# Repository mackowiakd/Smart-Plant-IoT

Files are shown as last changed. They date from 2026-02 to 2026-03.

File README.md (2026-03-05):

> 🎓 **Academic Project**: This project was developed for the *Microprocessor and Embedded Systems* course during the 5th semester of Computer Science at the **Silesian University of Technology** (Politechnika Śląska).

# Smart Plant Care IoT System 🌱

An end-to-end Internet of Things (IoT) solution for monitoring environmental parameters and autonomously managing plant hydration. The project spans custom hardware design (PCB), edge device firmware (ESP32-C3), and a full-stack web dashboard.

## 🌟 Key Features
* **Smart Autonomous Watering:** Activates a water pump based on custom-calibrated soil moisture data (`AIR_VALUE` & `WATER_VALUE`). The logic includes safety checks, such as preventing watering during low temperatures to protect the plant roots.
* **Extreme Power Optimization:** Heavily utilizes the ESP32 **Deep Sleep** mode. The system wakes up periodically, performs measurements, communicates with the server, and goes back to sleep, allowing for long-term operation on a standard 5V powerbank.
* **Fail-Safe Offline Mode (Fallback AP):** If the configured WiFi network is lost, the device automatically spawns its own Access Point (e.g., "Roslina SOS"). It serves a lightweight local HTML page (`WebPage.h`) directly to a smartphone, allowing the user to view telemetry without internet access.
* **Hybrid Timekeeping:** Combines internet time synchronization (NTP) with a battery-backed hardware Real-Time Clock (DS3231) to maintain time context and scheduling during power losses or offline periods.
* **Full-Stack SPA Architecture:** Telemetry is pushed via HTTP to a custom .NET backend, which seamlessly serves a modern React-based user dashboard.

## 🛠️ System Architecture & Tech Stack

### 1. Edge Device (Firmware & Hardware)
* **Microcontroller:** Seeed Studio XIAO ESP32-C3.
* **Sensors & Actuators:** * **BME280** (Temperature, Humidity, Atmospheric Pressure) via I2C.
  * **BH1750** (Light intensity/Lux) via I2C.
  * **DS3231** (Hardware RTC) via I2C.
  * **Capacitive Soil Moisture Sensor v1.2** via ADC.
  * 5V Water Pump controlled via MOSFET/Relay.
* **Firmware:** C++, PlatformIO, custom sleep/wake routines.

### 2. Web Application (Backend & Frontend)
* **Architecture:** Single Page Application (SPA) integration.
* **Backend:** C#, ASP.NET Core REST API for telemetry data ingestion and aggregation.
* **Frontend:** React.js, Vite, and Tailwind CSS for responsive data visualization.

## 📸 Project Gallery

smart_plant_hardware

  **Figure 1: Custom PCB & Hardware Assembly.** *The physical implementation of the project. I designed the schematic and routed the custom PCB using **KiCad** to seamlessly integrate the XIAO ESP32-C3 with various modules: an I2C environment sensor array (including BH1750), a battery-backed RTC, and the power delivery circuitry. The entire system is optimized to run autonomously on a standard 5V powerbank utilizing Deep Sleep cycles.*


  **Figure 1: Custom PCB & Hardware Assembly.** Showing the XIAO ESP32-C3 integration with environmental sensors and the watering unit running on powerbank supply.

 

https://github.com/user-attachments/assets/34abda69-28c0-408e-982a-c36de282d4bd

  **Figure 2: React Dashboard.** Visualizing real-time telemetry data (humidity, temperature, pressure, light) received from the .NET REST API.

https://github.com/user-attachments/assets/e299edc5-c103-400d-92fd-4557b35e483f

  **Figure 3: Emergency Offline Mode.** The lightweight captive portal/HTML page served directly by the ESP32 when external WiFi is unavailable.

## 🚀

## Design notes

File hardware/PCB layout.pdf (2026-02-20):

1. Wersja "BEZ WYLANEJ MASY" ( Top/Bottom )

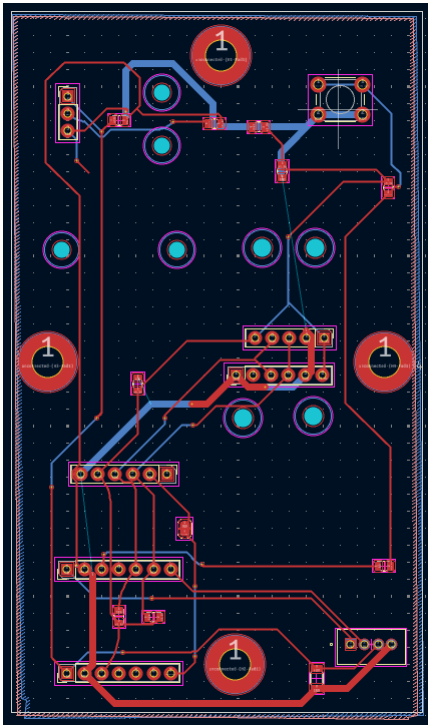
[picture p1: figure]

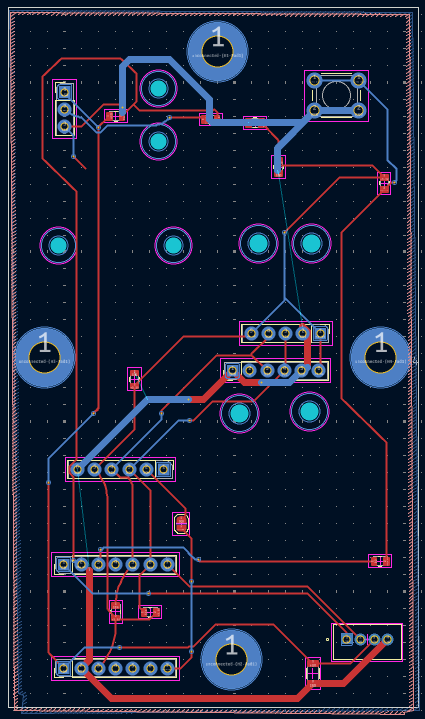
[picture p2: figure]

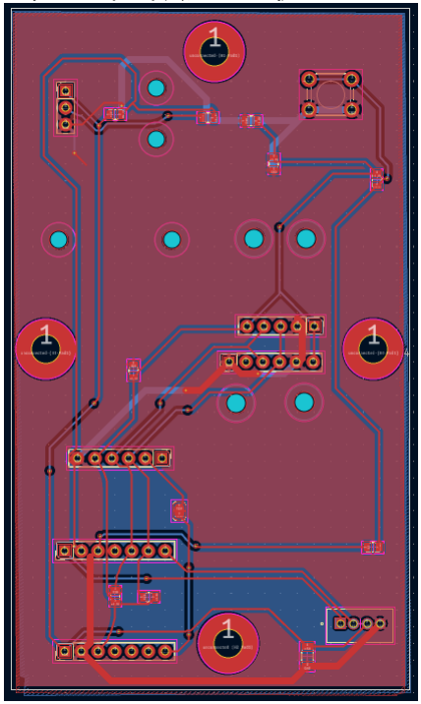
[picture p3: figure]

2. Wersja "Z WYLANĄ MASĄ" (Top/Bottom z masą)

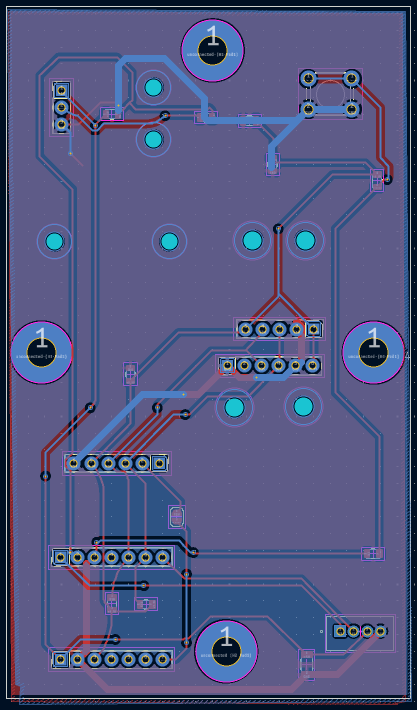
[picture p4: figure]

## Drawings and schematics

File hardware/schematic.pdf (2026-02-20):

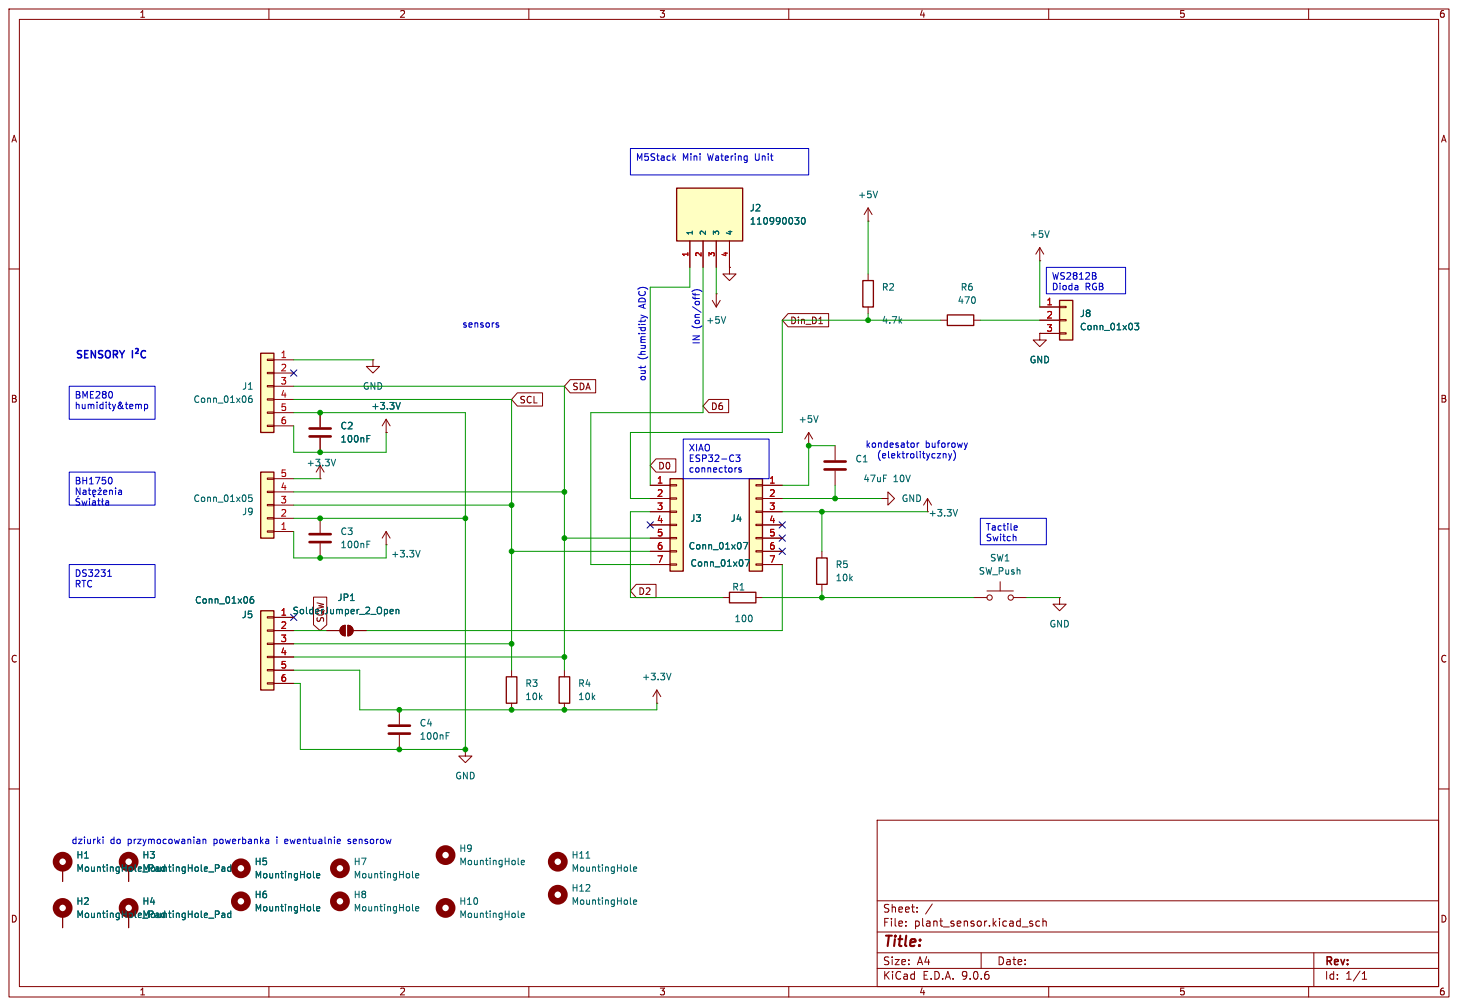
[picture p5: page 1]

4 4
5 5

Id: 1/1 Title: File: plant_sensor.kicad_sch Sheet: /

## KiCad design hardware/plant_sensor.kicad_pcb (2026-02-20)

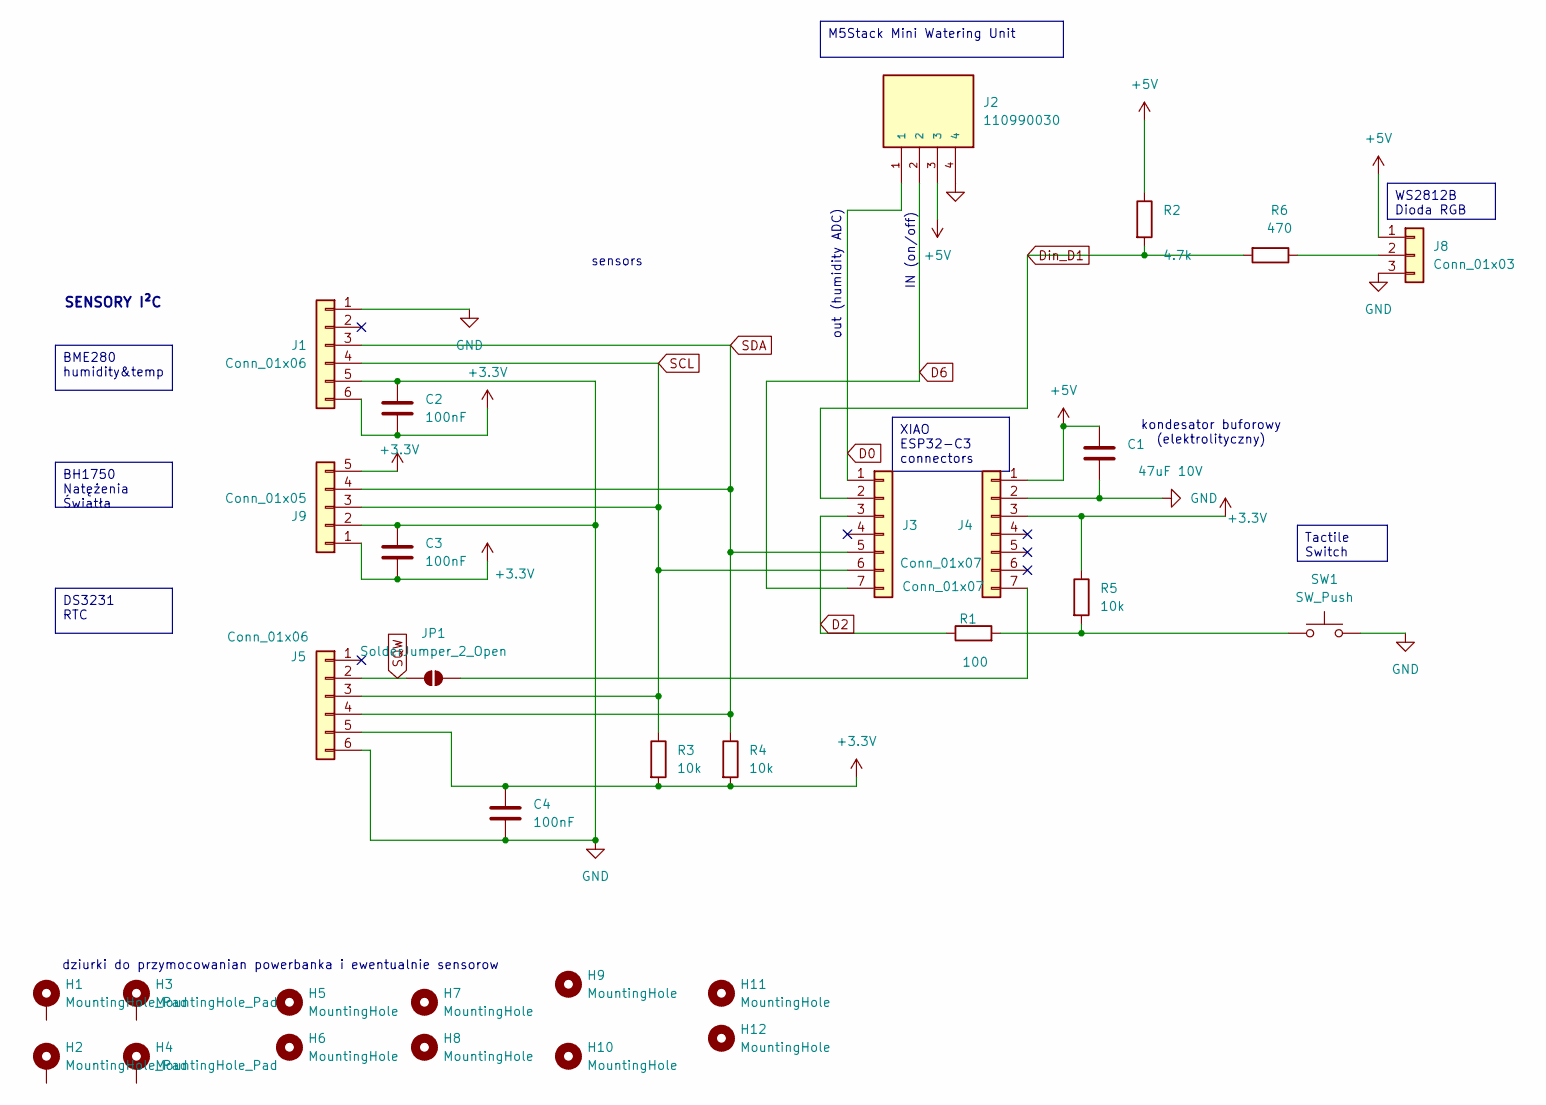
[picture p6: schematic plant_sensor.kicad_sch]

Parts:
C1: 47uF 10V; C_1206_3216Metric; LCSC Part # C13608
C2, C3, C4: 100nF; C_0805_2012Metric; LCSC Part # C49678
H1, H2, H3, H4: MountingHole_Pad; MountingHole_4.3mm_M4_Pad
H5, H6, H7, H8: MountingHole; MountingHole_2.7mm
H9, H10, H11, H12: MountingHole; MountingHole_2.5mm
J1, J5: Conn_01x06; PinHeader_1x06_P2.54mm_Vertical; LCSC Part # C50982
J2: 110990030; SEEED_110990030; PARTREV A; LCSC Part # C52230
J3, J4: Conn_01x07; PinHeader_1x07_P2.54mm_Vertical; LCSC Part # C2254
J8: Conn_01x03; PinHeader_1x03_P2.54mm_Vertical; LCSC Part # C124398
J9: Conn_01x05; PinHeader_1x05_P2.54mm_Vertical; LCSC Part # C2251
JP1: SolderJumper_2_Open; SolderJumper-2_P1.3mm_Open_RoundedPad1.0x1.5mm
R1: 100; R_0805_2012Metric; LCSC Part # C17408
R2: 4.7k; R_0805_2012Metric; LCSC Part # C17673
R3, R4, R5: 10k; R_0805_2012Metric; LCSC Part # C17414
R6: 470; R_0805_2012Metric; LCSC Part # C17710
SW1: SW_Push; SW_PUSH_6mm; LCSC Part # C318884

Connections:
+3.3V: C2.2, C3.2, C4.1, J1.6, J4.3, J5.5, J9.1, J9.5, R3.2, R4.2, R5.1
+5V: C1.1, J2.3, J4.1, J8.1, R2.1
D0: J2.1, J3.1
D2: J3.3, R1.1
D6: J2.2, J3.7
Din_D1: J3.2, R2.2, R6.2
GND: C1.2, C2.1, C3.1, C4.2, J1.1, J1.5, J2.4, J4.2, J5.6, J8.3, J9.2, SW1.2
unnamed: J4.7, JP1.2 (B)
unnamed: J8.2, R6.1
unnamed: R1.2, R5.2, SW1.1
SCL: J1.4, J3.6, J5.3, J9.3, R3.1
SDA: J1.3, J3.5, J5.4, J9.4, R4.1
SQW: J5.2, JP1.1 (A)

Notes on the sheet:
sensors
IN (on/off)
SENSORY I²C
dziurki do przymocowanian powerbanka i ewentualnie sensorow
kondesator buforowy (elektrolityczny)
out (humidity ADC)
M5Stack Mini Watering Unit
XIAO ESP32-C3 connectors
BME280 humidity&temp
WS2812B Dioda RGB
BH1750 Natężenia Światła
Tactile Switch
DS3231 RTC

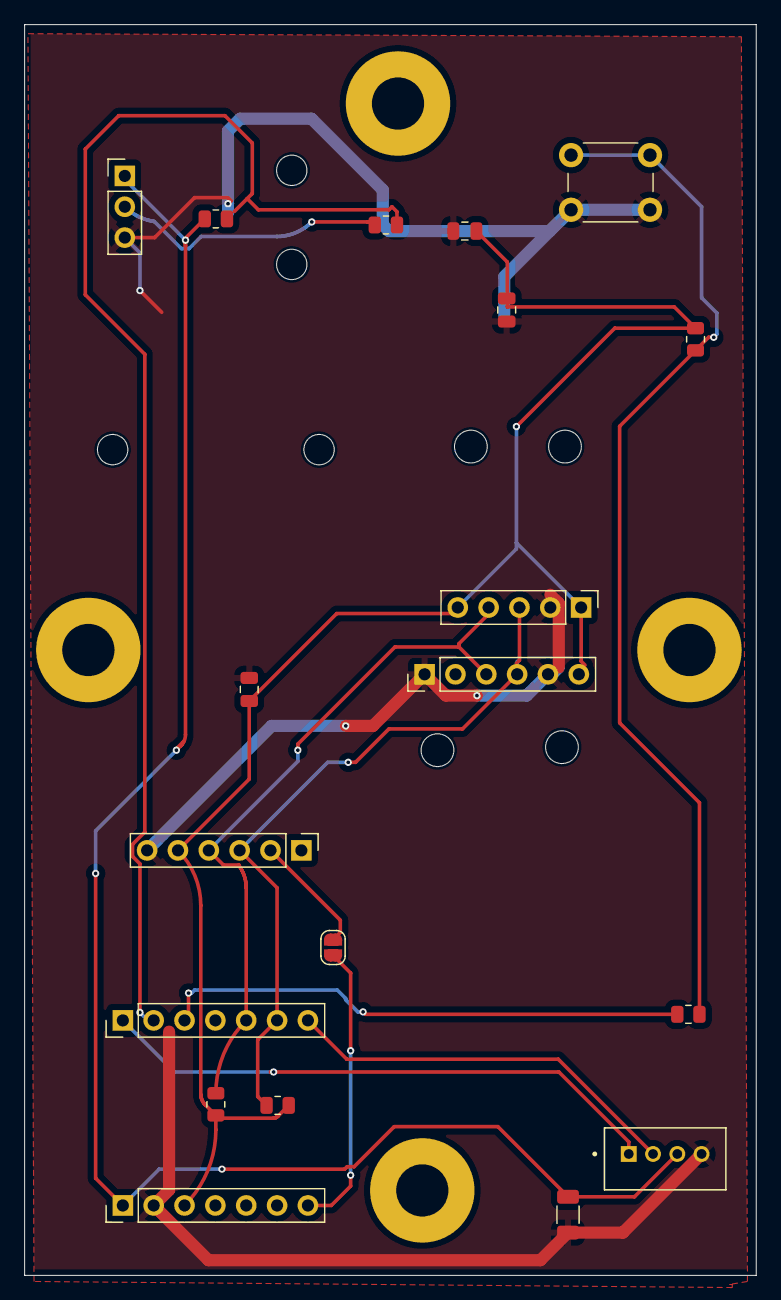
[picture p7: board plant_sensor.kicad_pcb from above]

Board: 2 copper layers, 60.2 x 103.0 mm, 31 parts (0 on the bottom side), 13 nets.

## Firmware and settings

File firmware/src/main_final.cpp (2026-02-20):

#include <Arduino.h>
#include "Logic/plant entity/PlantManager.h" 

// --- KONFIGURACJA ---
#define PIN_SDA 6
#define PIN_SCL 7
#define PIN_PUMP 21     
#define PIN_MOIST 2     
#define PIN_LED 3       
#define PIN_BTN 4       

// Obiekty
PlantManager manager(new Indicator(PIN_LED, PIN_BTN), new WateringUnit(PIN_PUMP, PIN_MOIST), new RealTimeClock());

// Zmienne
bool interactiveMode = true; // ZAWSZE TRUE - bo zawsze chcemy wejść do loop
unsigned long lastActivityTime = 0;

void setup() {
    Serial.begin(115200);
    
    // Safety delay (żebyś mogła wgrać kod w razie pętli resetów)
    long start = millis();
    while(!Serial && (millis()-start < 2000)); 
    delay(2000); // Dajmy 2s na start, nie 10s (szkoda czasu na prezentacji)

    Serial.println("\n--- POBUDKA SYSTEMU ---");
    
    // 1. Inicjalizacja sprzętu (WiFi/AP)
    manager.begin(true); 

    // 2. Dlaczego wstaliśmy? (Tylko dla informacji w logach)
    esp_sleep_wakeup_cause_t reason = esp_sleep_get_wakeup_cause();
    if (reason == ESP_SLEEP_WAKEUP_GPIO) {
        Serial.println(">> Powód: PRZYCISK.");
    } else {
        Serial.println(">> Powód: TIMER / RESET.");
    }

    // 3. PIERWSZY POMIAR (ZAWSZE!)
    // Wykonujemy go od razu, żeby mieć dane na start (dla WWW i C#)
    Serial.println("[Setup] Wykonuje pierwszy pomiar...");
    manager.runAutoCycle();

    // 4. PRZYGOTOWANIE DO PĘTLI
    lastActivityTime = millis();
    
    // UWAGA: Tu NIE MA manager.sleep()! 
    // Pozwalamy procesorowi wyjść z setup() i wpaść naturalnie do loop().
}

void loop() {
    
    // 1. Obsługa sieci (Server WWW / WiFi)
    manager.updateNetwork();
    
    // 2. Obsługa przycisku
    manager.handleUI();
    manager.handleAPVisuals(); 

    // 3. Reset licznika czasu przy aktywności (klikaniu)
    if (digitalRead(PIN_BTN) == LOW) {
        lastActivityTime = millis();
    }

    // 4. CYKLICZNE POMIARY W PĘTLI (co 10 sekund)
    // Dzięki temu na prezentacji wykresy w C# będą "żyły"
    
    if (millis() - manager.get_lastMeasure() > 10000) {
        manager.set_lastMeasure(millis());
       
        manager.runAutoCycle(); 
    }

    
    
    // 5. TIMEOUT (Inteligentne usypianie)
    // Jeśli AP (Awaria) -> 6 minut (30o tys ms)
    // Jeśli WiFi (Sukces) -> 5 minuty (180000 ms) - czas na pokazanie wykresów
    unsigned long timeout = manager.isAPmode() ? 300000 : 180000;

    if (millis() - lastActivityTime > timeout) {
        Serial.print("[LOOP] Czas aktywnosci minal (");
        Serial.print(timeout/1000);
        Serial.println("s). Ide spac.");
        
        // Dopiero tutaj idziemy spać!
        // Budzik na 3 minut (dla testów) lub 180 min (finalnie)
        manager.sleep(3); 
    }
    
    
    delay(20); 
    
}

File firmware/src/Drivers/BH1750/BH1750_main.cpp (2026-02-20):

// #include <Arduino.h>
// #include "LightSensor.h" // Dołączamy naszą klasę

// // Definiujemy piny
// #define PIN_SDA 6
// #define PIN_SCL 7

// // Tworzymy obiekt naszego czujnika
// LightSensor mojCzujnik(PIN_SDA, PIN_SCL);

// void setup() {
//     Serial.begin(115200);
//     delay(2000);
//     // Czekamy na serial monitor
//     NewFunction();
//     Serial.println("Start systemu...");

//     // Uruchamiamy czujnik używając naszej metody
//     if (mojCzujnik.begin()) {
//         Serial.println("Czujnik BH1750 dziala!");
//     } else {
//         Serial.println("Blad czujnika!");
//         while(1); // Stop
//     }
// }

// void NewFunction()
// {
//     long startWait = millis();
//     while (!Serial && (millis() - startWait < 6000))
        
//         delay(1000);
// }

// void loop() {
//     // Czytamy wartość
//     float lux = mojCzujnik.readLux();
    
//     Serial.print("Swiatlo: ");
//     Serial.print(lux);
//     Serial.println(" lx");
    
//     delay(1000);
// }

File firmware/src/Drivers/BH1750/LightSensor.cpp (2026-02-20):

#include "LightSensor.h"

LightSensor::LightSensor(uint8_t addr, int sda, int scl) {
    _address = addr;
    // Ignorujemy sda/scl tutaj, bo Wire jest inicjowane globalnie w PlantManager
}

void LightSensor::sendCommand(byte cmd) {
    Wire.beginTransmission(_address);
    Wire.write(cmd);
    Wire.endTransmission();
}

bool LightSensor::begin() {
    // UWAGA: Nie robimy tutaj Wire.begin() ani Wire.end()!
    // Zakładamy, że PlantManager już uruchomił magistralę.
    
    // Tylko konfigurujemy czujnik (Twój kod):
    sendCommand(CMD_POWER_ON);
    delay(10); // Krótka przerwa dla stabilności
    sendCommand(CMD_MODE_H_RES);
    
    return true; 
}

float LightSensor::readLux() {
    // Pytamy o 2 bajty (Twój kod z pętli loop)
    int count = Wire.requestFrom((int)_address, 2);

    if (count == 2) {
        byte b1 = Wire.read();
        byte b2 = Wire.read();
        
        uint16_t val = ((b1 << 8) | b2);
        return val / 1.2; // Twoje przeliczenie
    } else {
        // Jeśli błąd, próbujemy go "kopnąć" ponownie (z Twojego kodu)
        // Serial.println("BH1750: Brak danych, restartuje pomiar...");
        sendCommand(CMD_POWER_ON);
        sendCommand(CMD_MODE_H_RES);
        return -1.0; // Kod błędu
    }
}
/*
#include "LightSensor.h"

LightSensor::LightSensor(byte address, int sda, int scl) {
    _address = address;
    _sdaPin = sda;
    _sclPin = scl;
}




void LightSensor::sendCommand(byte cmd) {
    Wire.beginTransmission(_address);
    Wire.write(cmd);
    Wire.endTransmission();
}

bool LightSensor::begin() {
    // Twoja sprawdzona sekwencja startowa
    Wire.end();
    Wire.setPins(_sdaPin, _sclPin);
    
    if (!Wire.begin()) {
        return false; // Błąd I2C
    }

    // Włączenie czujnika
    sendCommand(CMD_POWER_ON);
    sendCommand(CMD_MODE_H_RES);
    
    return true;
}





*/

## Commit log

2026-02-20 Initial commit: struktura End-to-End (Firmware, Web App, Hardware)
    [plant_sensor.kicad_pcb, plant_sensor.kicad_sch]
2026-02-24 Add custom PCB image and description to README
    Updated project gallery with a new image and description.
